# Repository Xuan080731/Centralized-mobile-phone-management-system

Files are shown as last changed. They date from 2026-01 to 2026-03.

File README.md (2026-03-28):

# 📱 集中式手機管理系統 (Centralized mobile phone management system)

> 一個集中式手機管理系統，使用 Web App 監控手機的放置狀態和環境狀態，並將資料記錄在 Google 試算表中，同時可利用 RFID 解鎖或 Web App 遠端、定時解鎖。

## 📖 專案簡介 (Introduction)

近年來，全球教育界為提升學生專注力，對於校園手機使用的規範日益嚴格。然而，傳統的手機保管箱僅具備物理存放功能，缺乏即時狀態監控、環境感測預警與數位化管理能力，若發生手機未歸位或意外狀況，管理端難以即時掌握。

基於此痛點，本專案開發了一套整合環境感測與雲端監控之集中式手機管理系統，採用 **ESP32 與 Mega2560 雙主控協作架構**，不僅實現了 20 個手機槽位的精準狀態監控，更結合了雲端 Web App，提供校園或特定高保密場所一套高效、模組化且易於維護的手機集中管理方案。

## ✨ 核心特色 (Key Features)

* **🧠 異質雙主控架構 (Dual-MCU Architecture)**
  由 Arduino Mega2560 負責 20 路微動開關的底層 I/O 實時輪詢，並交由搭載 FreeRTOS 的 ESP32 進行邊緣運算與雲端通訊，徹底解決單晶片 I/O 不足與聯網阻塞問題。
* **☁️ 可視化網頁監控 (Serverless Web Dashboard)**
  完全免架設實體伺服器！後端採用 Google Apps Script (GAS) 構建，狀態與歷史紀錄即時寫入 Google Sheets，並提供可視化的響應式 Web App，管理員可隨時隨地遠端監控手機放置情況和環境狀態並執行遠端解鎖或定時排程。
* **🔐 多元安全門禁 (Secure Access Control)**
  支援授權 RFID 卡片感應解鎖、Web App 遠端一鍵解鎖，以及自訂時間的自動排程解鎖，配合磁簧開關實現防呆關門自動上鎖。
* **🚨 主動式災防預警 (Active Emergency Response)**
  整合 MQ-135 氣體感測器即時偵測空氣品質與火災煙霧（如手機鋰電池自燃）；同時接入 **台灣中央氣象局 (CWA) 地震速報 API**。當遭遇異常煙霧或四級以上有感地震等危急情況時，系統將觸發蜂鳴器警報並強制自動解鎖，確保人員逃生時能及時取回手機，保障生命財產安全。

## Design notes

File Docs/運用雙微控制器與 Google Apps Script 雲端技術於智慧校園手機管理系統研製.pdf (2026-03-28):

運用雙微控制器與 Google Apps Script 雲端技術於智慧校園手機管理系統之研製 壹、前言

一、研究動機

近年來，全球教育界對於學生在校使用手機的限制日益趨嚴，旨在改善學 習環境並提升學生的專注力。從歐美多國到我國教育部，紛紛加強了相關政策 的推動。然而，傳統的手機保管箱僅能提供物理上的集中存放，缺乏即時監 控、教室環境感測與數位化管理的能力。一旦發生手機未歸位或其他狀況，管 理人員難以即時掌握。

基於此社會需求與技術缺口，本專題發想出「智慧手機保管箱」，目標是 設計一個具備手機放置監控、環境感測預警、RFID 解鎖、遠端解鎖、定時解 鎖及遠端 Web App 管理功能的智慧化解決方案，以滿足學校、會議室或實驗 室等場所對手機集中管理的嚴格要求。

二、研究目的

本研究旨在研製一套「主動式智慧手機管理系統」，具體目的如下：

(一)實現即時狀態監控：透過微動開關感測器，精確監測 20 個手機槽位的放置狀 態，並在外殼上的 1~20 個 LED 燈和 LCD 螢幕上與網頁即時顯示。

(二)建立安全存取機制：整合 RFID 讀取模組與推拉式電磁鎖和需 PIN 碼驗證的遠 端、定時解鎖，確保只有經過授權的人員才能解鎖保管箱。

(三)開發雲端管理平台：利用 Google Apps Script 建立 Web App 監控系統，實現遠端 查看手機狀態、溫度等環境資訊和遠端、定時解鎖，並將數據紀錄至 Google Sheets。

(四)提升安全性與主動應變能力: 整合 MQ-135 煙霧感測與中央氣象局 API 地震偵 測。當偵測到火災煙霧或四級以上地震時，系統會強制解鎖保管箱並觸發蜂鳴器警 報，確保人員能迅速取回手機，保障生命財產安全。

貳、文獻探討

一、雙微控制器架構與系統強健性分析

在物聯網（IoT）裝置的開發中，網路傳輸與硬體控制的資源分配一直是關鍵難題。根據

## Niedermaier、Merli 與 Sigl（2019）在《A Secure Dual-MCU Architecture for Robust Communication of IIoT Devices》研究中指出，傳統的單一微控制器（Single-MCU）架構在

處理複雜的加密通訊協定（如 TLS/HTTPS）時，往往會佔用大量的 CPU 運算週期，進而 導致對硬體感測器的控制產生延遲或中斷（Blocking），嚴重影響系統的即時性。

該研究進一步提出「雙微控制器架構（Dual-MCU Architecture）」作為解決方案，主張

## 將「網路通訊任務（Communication Tasks）」與「實體控制任務（Physical Control

Tasks）」進行硬體層級的解耦（Decoupling）。透過專屬的通訊晶片處理外部連線，主控制

晶片則能專注於感測器讀取與致動器控制。研究結果證實，此架構能顯著提升系統在網路不 穩定或高負載環境下的強健性（Robustness）與可用性（Availability）。

本研究在系統設計上導入 ESP32 雙核心（Dual-Core）平行運算技術。利用 FreeRTOS 進行任務調度，將 ESP32 的 核心 1（Core 1） 規劃為「本地控制核心」，專責處理 RFID 身分識別、電子鎖控制及感測器數據讀取，確保硬體操作達到即時響應；同時將 核心 0 （Core 0） 指派為「雲端通訊核心」，專門負責耗時的 Google Sheets API 連線與資料上傳 任務。此一分流設計確保了即便系統正在進行網路傳輸或遭遇網路壅塞，使用者的刷卡開鎖 等在地端操作體驗依然流暢不受影響。

二、雲端資料庫技術之選用與分析

在物聯網系統的後端資料庫選擇上，傳統的關聯式資料庫（如 MySQL、SQL Server） 雖然功能強大，但往往伴隨著高昂的伺服器架設與維護成本，對於校園專題或中小型應用而 言門檻過高。相較之下，採用雲端試算表作為輕量級資料庫已成為新興趨勢。

## 根據 Kumar、Sudharani 與 Jayavardhan（2025）在《Build Your Own RFID Attendance System Using Arduino, ESP32, and Google Sheets》的研究指出，整合 Arduino

與 ESP32 架構並利用 Google Sheets 作為後端資料庫，不僅具備零成本與高可及性的優 勢，更能透過 Google Apps Script API 實現高可靠度的即時數據登錄與監控。該研究證實， 此架構能有效消除本地端伺服器的維護負擔，同時提供穩定的數據雲端同步功能。

本研究參採此一概念，利用 Google Sheets 取代傳統伺服器，將 ESP32 的數據透過 HTTPS 協定直接寫入雲端，實現低成本且易於管理的智慧化系統。

三、智慧置物櫃與物聯網監控之應用

## Umadi 等人（2023）在《Smart E-Locker System using IoT》研究中提出了一種基於

RFID 與物聯網技術的智慧電子置物櫃系統。該研究指出，傳統置物櫃缺乏即時監控能力， 而透過整合微控制器與雲端平台（如 Adafruit Cloud），系統不僅能記錄使用者的存取日誌， 還能在偵測到未授權的 RFID 標籤時觸發警報並發送通知。這證實了將「實體鎖頭」與 「雲端紀錄」結合，能顯著提升校園或公共場域資產管理的安全性與便利性，此論點支持了 本研究將手機保管箱雲端化的設計思路。

參、研究方法

一、研究步驟

本研究的製作流程從初步構想到最終成品，歷經需求分析、設計、開發、測試與整合等 多個階段。詳細步驟如下：

（一） 初步構想與需求分析：
1. 確立研究動機：針對校園手機管理普遍存在的挑戰，如傳統保管箱缺乏效率、安全 性不足等問題，確立開發一套智慧化管理系統的目標。
2. 功能規格定義：明確系統需具備的核心功能，包括即時監控手機放置狀態、RFID 授 權解鎖、遠端解鎖、定時解鎖、遠端 Web App 管理、以及偵測到煙霧或地震等緊 急情況下的自動解鎖與警報功能。
（二） 系統設計：
1. 硬體選型：根據功能需求，選定核心微控制器（ESP32 與 Arduino Mega 2560）、感 測器（微動開關、RFID RC522、MQ-135、DHT11）、致動器（電磁閥）及其他電子 元件。
2. 架構設計：採用雙微控制器架構，將本地即時控制與雲端通訊任務分離，確保系統 的穩定性與反應速度。同時設計了包含感知層、控制層與應用層的三層式系統架 構。
3. 電路設計：使用 Fritzing 等工具繪製詳細的電路圖，規劃各元件之間的接線與供電 方式。
4. 機構設計：使用 Thinkercad 進行 3D 建模，設計保管箱的外殼與內部 20 格手機槽 位，並規劃雷射切割的板材。
（三） 開發與製作：
1. 硬體組裝：進行雷射切割、組裝保管箱外殼，並根據電路圖焊接、連接所有電子元 件。

## 2. 韌體開發：使用 Arduino IDE 撰寫 ESP32 與 Arduino Mega 2560 的程式碼，實現感測

器數據讀取、雙晶片 UART 通訊、RFID 驗證、電磁鎖控制等功能。

## 3. 雲端平台開發：利用 Google Apps Script 建立後端伺服器，並設計 Google Sheets 作

為資料庫，用於接收並儲存來自 ESP32 的數據。同時開發 Web App 前端介面，實 現遠端監控與管理。
（四） 測試與驗證：
1. 單元測試：對各個硬體模組（如 RFID、微動開關）與軟體功能（如雲端上傳）進行 獨立測試，確保其正常運作。
2. 整合測試：將所有軟硬體整合，進行全面的系統測試，包括測試雙 MCU 架構下的 效能、雲端資料同步的延遲與成功率等。
3. 壓力測試：模擬多人同時使用或網路不穩定的情況，測試系統的穩定性與強健性。

（五） 修正與優化：
根據測試結果，對硬體電路、軟體程式碼或系統架構進行調整與優化，例如優化程 式演算法以縮短反應時間等。

圖一、研究步驟甘特圖

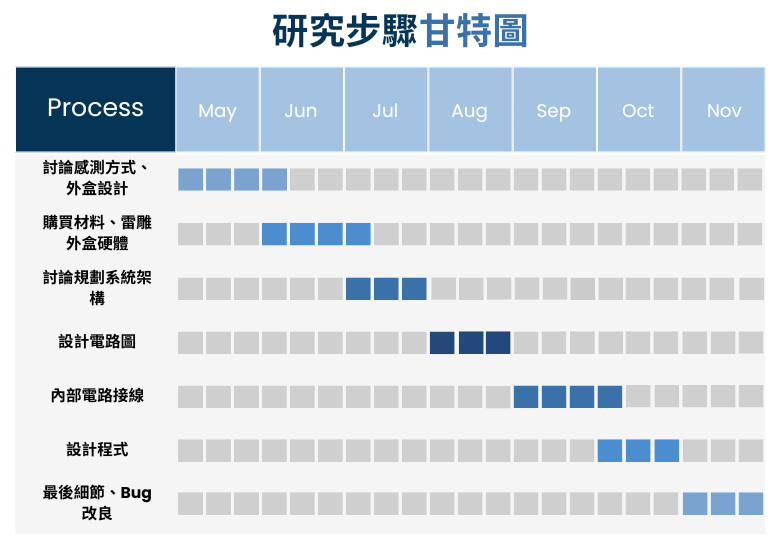
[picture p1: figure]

資料來源:使用 Canva 自行製作

圖二、初步設計模型 | 圖三、實際雷雕硬體

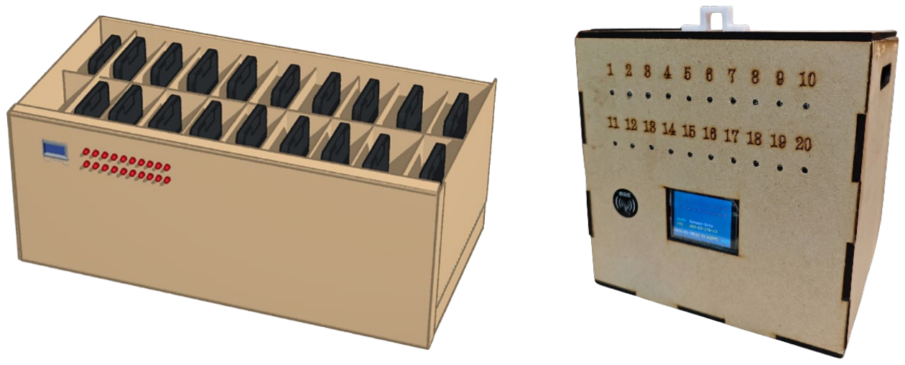
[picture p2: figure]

資料來源:使用 Thinkcad 設計初步模型 | 資料來源:自行拍攝

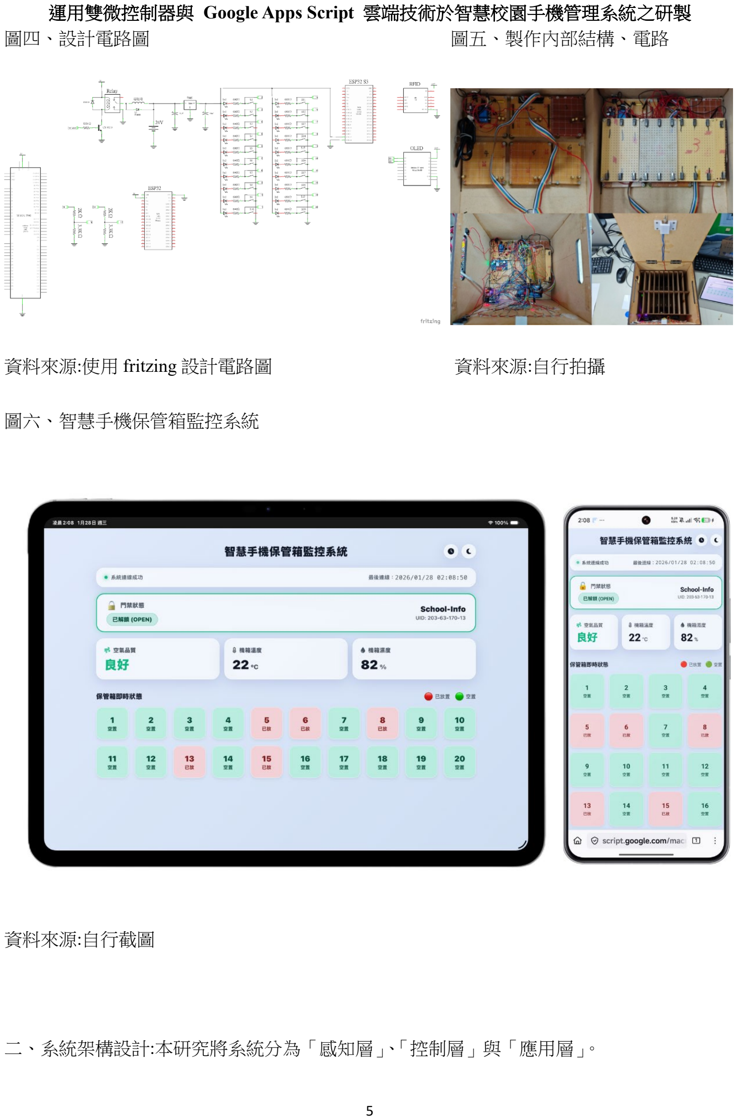
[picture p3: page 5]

圖四、設計電路圖 | 圖五、製作內部結構、電路
資料來源:使用 fritzing 設計電路圖 | 資料來源:自行拍攝

圖六、智慧手機保管箱監控系統

資料來源:自行截圖

二、系統架構設計:本研究將系統分為「感知層」、「控制層」與「應用層」。

(一) 感知層:此層負責實體環境與硬體狀態的數據採集，並執行身分識別

1. 手機狀態偵測：於 20 個手機櫃位內部各配置獨立微動開關，當手機置入或取出時觸發 物理開關，將實體動作轉換為數位高低電位訊號。
2. 身分識別模組：採用 RFID RC522 射頻識別模組，透過讀取使用者授權 UID，作為開 啟電子鎖安全驗證。
3. 環境安全感測：整合 MQ-135 氣體感測器與 DHT11 溫濕度感測器，即時監控保管箱 周遭的空氣品質、煙霧感測與溫濕度變化。

(二) 控制與運算層:為解決單一微控制器處理複雜任務造成的阻塞問題與腳位不夠問題，

採用雙微控制器協同架構，包含兩大運算核心。

## 1. I/O 協同處理單元 (Arduino Mega 2560)： 作為放置訊號採集，專責執行 20 個櫃位微

動開關的高頻率輪詢（Polling）掃描。其負責將龐大且零碎的 I/O 訊號預處理後，轉 換為特定格式之字串，透過 UART 序列埠穩定傳送至 ESP32 主控單元。

2. 通訊主控單元 (ESP32)： 作為系統的運算大腦與聯網樞紐。藉助其內建的 FreeRTOS 作業系統實現多工處理 ：
- Core 1 (即時控制)： 負責解析 Mega 2560 傳入之字串、處理 RFID 驗證、驅 動 24V 電磁閥執行解鎖動作，並同步控制 2.8 吋 SPI LCD 顯示螢幕及 20 顆外部 LED 指示燈，確保本地端操作具備極低延遲 。
- Core 0 (網路通訊)： 專責透過 Wi-Fi 建立 HTTPS 加密連線，負責將彙整後 之感測數據與系統狀態封裝，利用 HTTP GET 請求上傳至雲端；同時背景查 詢中央氣象署 API，判斷地震等突發狀況以觸發緊急安全機制 。

(三) 應用與儲存層: 此層負責雲端數據處理、持久化儲存與遠端人機介面互動：

## 1. 雲端伺服器 (Google Apps Script)：作為後端處理中心，接收並解析 ESP32 傳送之

RESTful API 請求。除了處理資料上傳外，亦負責下發遠端解鎖或定時解鎖指令給 ESP32。
2. 資料庫 (Google Sheets)： 作為輕量級雲端資料庫，即時且永久性地記錄 20 個槽位之狀 態、環境溫濕度、空氣品質指數以及 RFID 或遠端解鎖之時間與人員歷史資訊，便於管理端 進行查詢。
3. 可視化管理介面 (Web App)： 透過 HTML5/CSS3 開發響應式網頁（RWD），並結合密 碼（PIN 碼）驗證機制。提供教師或管理員於任何瀏覽器上，直觀且即時地檢視手機放置狀

態（綠燈/紅燈）、查閱環境資訊，並執行遠端授權、定時解鎖操作。

圖七、系統架構圖

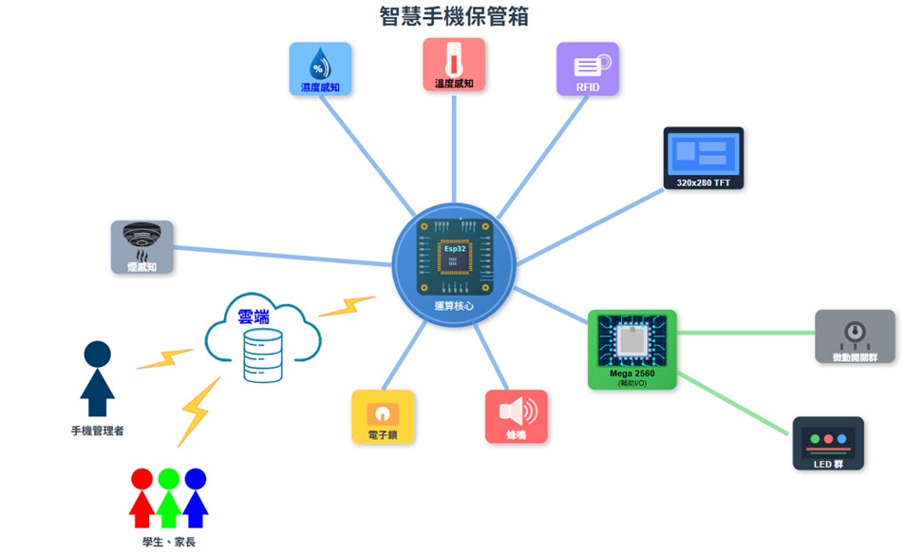
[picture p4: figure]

資料來源:自行製作

三、製作材料與硬體清單

表一、製作材料與硬體清單

類 別 | 項目 | 數 量 | 功能說明 | 價格 (NTD)
主 控 單 元 | ESP32 開發板 | 1 | 負責雙核心分流、WiFi 連線與 HTTPS 雲端資料上傳、控制電磁鎖、驅動 LCD 顯示。 | $150

類 別 | 項目 | 數 量 | 功能說明 | 價格 (NTD)
主 控 單 元 | Arduino Mega 2560 | 1 | 負責掃描 20 個櫃位微動開關狀態，具 備充足 I/O 腳位。 | $350
感 測 元 件 | RFID RC522 模 組 | 1 | 執行使用者身分識別與解鎖驗證。 | $60
感 測 元 件 | 微動開關 (KW12-3) | 20 | 安裝於櫃位內，偵測手機是否確實放 入。 | $60
感 測 元 件 | 溫濕度感測器 (DHT11) | 1 | 溫濕度感測。 | $15
感 測 元 件 | 空氣質量感測器 (MQ-135) | 1 | 空氣品質、氣體檢測。 | $50
感 測 元 件 | 磁簧開關 | 1 | 偵測箱門實體開關狀態，確保門關妥後 才執行電磁鎖閉鎖。 | $45

類 別 | 項目 | 數 量 | 功能說明 | 價格 (NTD)
控 制 元 件 | 電磁閥 (24V) | 1 | 執行櫃門實體解鎖動作。 | $250
輸 出 模 組 | 2.8 吋 SPI LCD 顯示模組 | 1 | 即時顯示解鎖狀態與手機放置狀態等資 訊。 | $120
輸 出 模 組 | 高亮度紅色 LED | 20 | 20 顆 LED 對應保管箱的 20 個格 位，作為狀態指示燈，用來即時顯示每 個格子是否已放入手機（佔用或空閒狀 態），讓使用者一目了然。 | $20
輸 出 模 組 | 有源蜂鳴器 | 1 | 提供刷卡、解鎖之操作音效提示；於偵 測到異常氣體或地震時發出警報音。 | $15
電 源 系 統 | 680 歐姆電阻 | 20 | 負責限制流經 LED 的電流大小，保護 LED 不會因為電流過大而燒毀。 | $5
電 源 系 統 | 2K、3.3K 歐姆 電阻 | 1 | 負責解決 Arduino Mega 2560 與 ESP32 工作電壓不同（邏輯電位不匹配）的問 題，保護 ESP32 不被燒毀。 | $1

類 別 | 項目 | 數 量 | 功能說明 | 價格 (NTD)
電 源 系 統 | XL4015 可調降 壓電源模塊 | 1 | 將用於電磁閥的 24V 電源轉為其他元件 可承受的 5V 電源。 | $200
電 源 系 統 | 24V5A 電源適 配器 | 1 | 用於供電。 | $200
機 構 材 料 | 杜邦線 | 100 | 連接各個元件。 | $100
機 構 材 料 | PCB 萬用電路 板 | 7 | 焊接/放置各種電路元件。 | $100
機 構 材 料 | 合成木板外盒 | 1 | 系統載體與手機放置格位。 | $1000
總 計 | | | 本系統研製總材料成本 | $2740

資料來源:自行計算

肆、研究分析與結果

一、雙微控制器與單晶片之效能比較

本研究實際測試「單晶片直接聯網」與「雙 MCU 架構」在操作反應時間上的差異。

表二、實際測試「單晶片直接聯網」與「雙 MCU 架構」在操作反應時間上的差異

測試項目 | 單晶片架 構 | 本研究雙 MCU 架 構 | 效能差異分 析
放置/拿取手機反應時間 (放入偵測到 LCD 顯示) | 約 1.85 秒 | 0.15 秒 | 快 12 倍
手機箱解鎖時間 (刷卡到電磁鎖彈開) | 約 3.12 秒 | 0.18 秒 | 快 17 倍
上傳顯示延遲 (動作發生到 Google Sheet 出現 資料) | 約 9 秒 | 4.4 秒 | 快 2 倍

資料來源:自行實驗結果

二、與傳統保管箱之比較分析

為凸顯本研究所開發之智慧校園手機管理系統的實用性與創新價值，我們將其與傳統的校園 手機保管箱進行多面向的比較分析。傳統保管箱雖然在各地校園行之有年，但其功能單一， 僅提供基本的集中收納，缺乏現代教育管理所需的智慧化與安全性。詳細比較如下表所示：

表三、與傳統保管箱之比較分析

功能 面向 | 傳統手機保管箱 | 本研究之智慧校園手機管理系統
狀態 監控 | 無法得知手機是否確實 放入 | 即時監控：透過 Web App 與 LED 燈號，可立即掌握每 個槽位的放置狀態。
管理 方式 | 人工點名、鑰匙管理 | 雲端平台：提供 Web App，讓管理者可遠端即時查看、 管理，並自動記錄存取日誌。
存取 安全 | 僅有簡易機械鎖，鑰匙 易遺失或複製 | 多重驗證：整合 RFID 卡片授權與遠端 PIN 碼解鎖，安 全性高。
緊急 應變 | 無 | 主動預警：整合煙霧與地震偵測，發生緊急狀況時自動 解鎖以供取出手機並發出警報。
管理 效率 | 耗時費力，需逐一確認 | 高效率：管理者可一目了然，大幅減少清點與管理的人 力成本。
擴充 彈性 | 固定規格，無法擴充 | 模組化設計：可根據班級人數需求，彈性擴充管理容 量。

資料來源:經驗統整

伍、研究結論與建議

一、結論

本研究成功研製一套基於 ESP32 與 Arduino Mega 2560 雙微控制器驅動之校園智慧手 機管理系統。實驗結果證實，透過雙核心任務分流架構，本系統能有效解決單晶片聯網時的 阻塞問題，將操作反應時間大幅縮短至 0.15 秒以內。在硬體架構方面，本系統採用模組化 設計，雖本研究之原型機以 20 格作為功能驗證，但其 I/O 控制邏輯具備高度可擴充性。 在實際應用場域中，僅需串聯偵測模組即可將管理容量擴充至標準班級規模（如 30 格或更 多），而無須更動核心控制系統。本研究不僅以低於市售電子櫃 2 倍之成本（約新台幣 2700 元）達成智慧化與集中式管理之目標，更大幅提升了校園手機管理的清點效率與安全 性。

二、建議

(一)系統管理介面之優化

建議未來可開發專屬的行動裝置應用程式（APP），整合推播通知功能，當學生逾時未放 入手機時，系統可主動發送訊息提醒管理員，從被動監控轉為主動預警。

(二)導入生物辨識功能

本研究目前採用 RFID 技術作為主要辨識載具，雖具備操作簡便之優點，但仍可能面臨 管理員遺失卡片或代為刷卡之管理風險 。建議未來可規劃導入生物辨識模組，例如：
- 人臉辨識：利用 ESP32-CAM 模組結合輕量化 AI 運算模型（如 TinyML），在邊緣 端實現視覺辨識，確保存取者的身分為本人，進一步提升系統的安全性。

陸、參考文獻

## Niedermaier, M., Merli, D., & Sigl, G. (2019). A Secure Dual-MCU Architecture for Robust

Communication of IIoT Devices. arXiv preprint arXiv:1908.04133.

Kumar, L. N., Sudharani, K., & Jayavardhan, L. (2025). Build your own RFID attendance system using Arduino, ESP32, and Google Sheets. International Journal of Scientific Development and Research, 10(8), 448-455.

Umadi, K. R., Inchara, S. M., Jyothi, E., & Narendramath, E. (2023). Smart E-Locker System using IoT. 2023 International Conference on Intelligent Data Communication Technologies and Internet of Things (IDCIoT), 415-419.

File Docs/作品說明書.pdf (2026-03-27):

## 智慧手機保管箱說明書

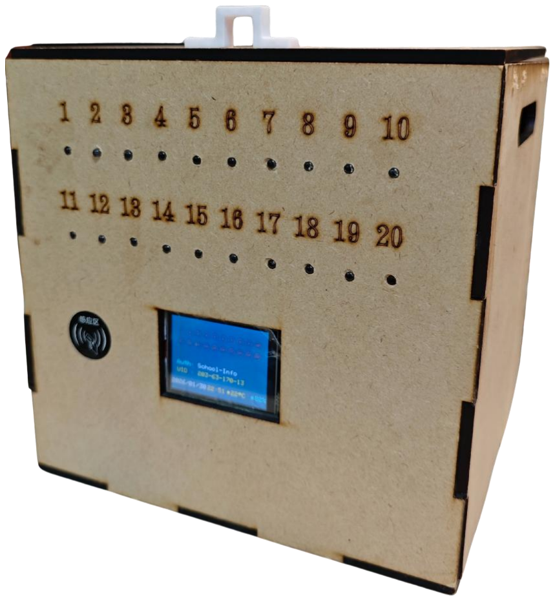
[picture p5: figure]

## 關 鍵 詞： 物聯網、手機管理、環境監控

目錄

項目 | 頁數

### 壹、 創意動機及目的

| 一、 動機 - - - - - - - - - - - - - - - - - - - - - - - - - - 1
| 二、 目的 - - - - - - - - - - - - - - - - - - - - - - - - - - 1

### 貳、 作品特色及創意特質

| 一、 輕量級雲端監控 Web App - - - - - - - - - - - 1,2
| 二、 直觀方便檢視放置狀態 - - - - - - - - - - - - - 2
| 三、 安全性與主動應變能力 - - - - - - - - - - - - - 3
| 四、 模組化與實用性設計 - - - - - - - - - - - - - - 3

### 參、 創意發想與設計過程

| 一、 問題探索與需求蒐集 - - - - - - - - - - - - - - 4
| 二、 設計流程 - - - - - - - - - - - - - - - - - - - - - - 4~6

### 肆、 設計相關原理

| 一、 雙主控單元協作架構 - - - - - - - - - - - - - - 7
| 二、 雲端數據傳輸原理 - - - - - - - - - - - - - - - - 8
| 三、 MQ-135 氣體數值演算法與動態校正邏輯 8,9
| 四、 TFT LCD 自製中文轉點陣生成工具 - - - - 9,10
| 五、 硬體結構與控制原理 - - - - - - - - - - - - - - 10,11

項目 | 頁數

### 伍、作品功用與操作方式

| 一、 作品功用 - - - - - - - - - - - - - - - - - - - - - - - 11,12
| 二、 操作方式 - - - - - - - - - - - - - - - - - - - - - - - 12

### 陸、製作歷程說明

| 三、 硬體製作流程 - - - - - - - - - - - - - - - - - - - 12~14
| 四、 軟體開發流程 - - - - - - - - - - - - - - - - - - - 14,15

柒、參考資料 - - - - - - - - - - - - - - - - - - - - - - - - - 15

### 壹、創意動機及目的

一、動機

近年來，全球教育界對於學生在校使用手機的限制日益趨嚴，旨在改善學習環 境並提升學生的專注力。從歐美多國到我國教育部，紛紛加強了相關政策的推 動。然而，傳統的手機保管箱僅能提供物理上的集中存放，缺乏即時監控、教 室環境感測與數位化管理的能力。一旦發生手機未歸位或其他狀況，管理人員 難以即時掌握。

基於此社會需求與技術缺口，本專題發想出「智慧手機保管箱」，目標是設計 一個具備手機放置監控、環境感測預警、RFID 解鎖及遠端 Web App 管理功能 的智慧化解決方案，以滿足學校、會議室或實驗室等場所對手機集中管理的嚴 格要求。

二、目的

(一)實現即時狀態監控：透過微動開關感測器，精確監測 20 個手機槽位的放置 狀態，並在外殼上的 1~20 個 LED 燈和 LCD 螢幕上與網頁即時顯示。

(二)建立安全存取機制：整合 RFID 讀取模組與推拉式電磁鎖和需 PIN 碼驗證的 遠端、定時解鎖，確保只有經過授權的人員才能解鎖保管箱。

(三)開發雲端管理平台： 利用 Google Apps Script 建立 Web App 監控系統，實 現遠端查看手機狀態、溫度等環境資訊和遠端、定時解鎖，並將數據紀錄至 Google Sheets。

(四)提升安全性與主動應變能力: 整合 MQ-135 煙霧感測與中央氣象局 API 地震 偵測。當偵測到火災煙霧或四級以上地震時，系統會強制解鎖保管箱並觸發蜂 鳴器警報，確保人員能迅速取回手機，保障生命財產安全。

### 貳、作品特色及創意特質

一、輕量級雲端監控 Web App

- 無需專門伺服器： 藉助 Google 服務的免費與穩定性，大幅降低了系統部 署與維護成本。

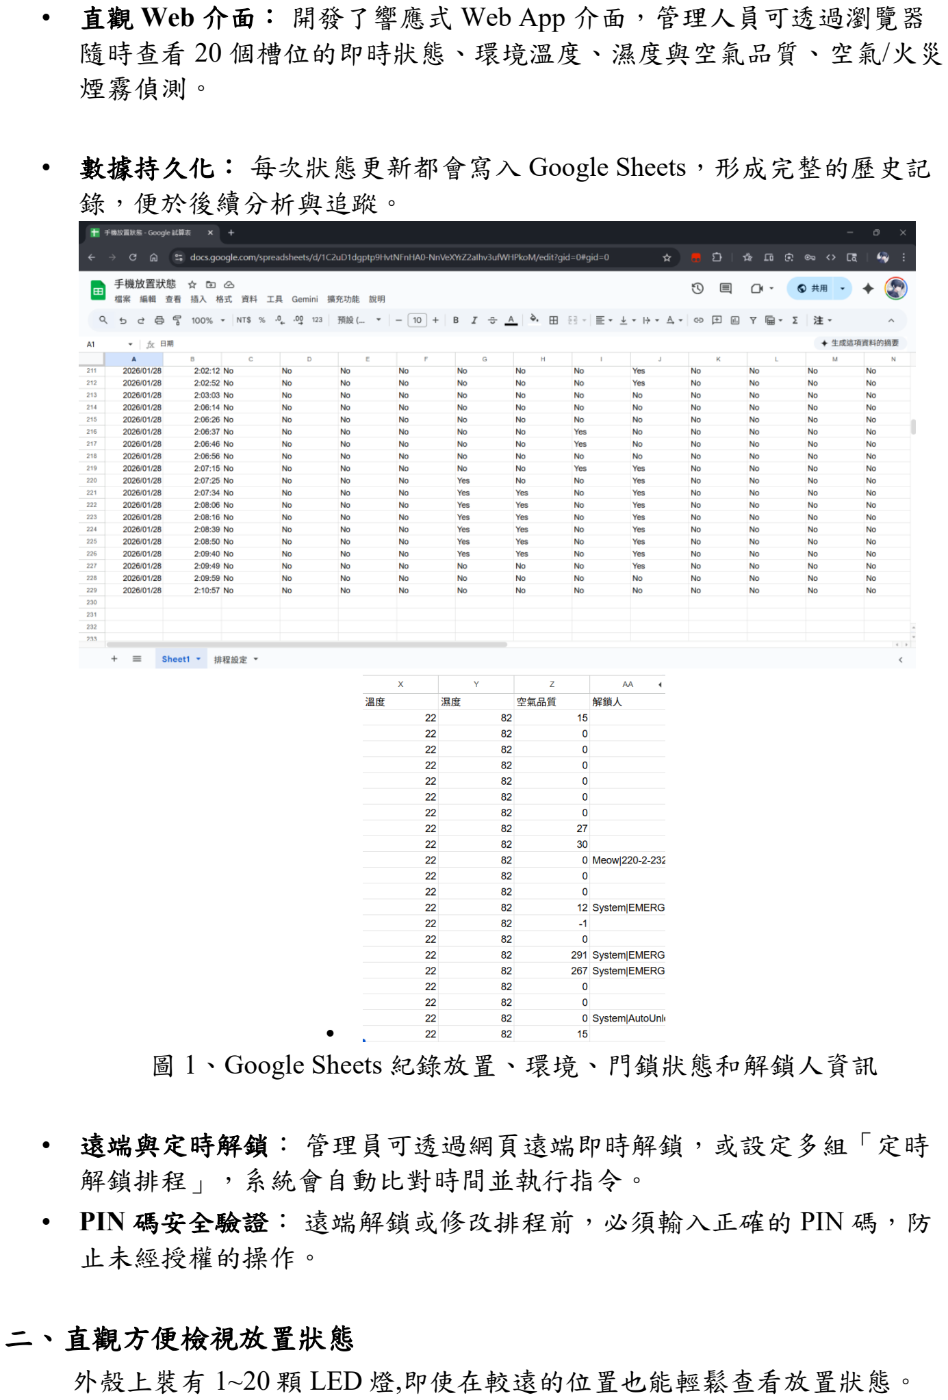
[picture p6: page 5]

- 直觀 Web 介面： 開發了響應式 Web App 介面，管理人員可透過瀏覽器 隨時查看 20 個槽位的即時狀態、環境溫度、濕度與空氣品質、空氣/火災 煙霧偵測。
- 數據持久化： 每次狀態更新都會寫入 Google Sheets，形成完整的歷史記 錄，便於後續分析與追蹤。

•
圖 1、Google Sheets 紀錄放置、環境、門鎖狀態和解鎖人資訊
- 遠端與定時解鎖： 管理員可透過網頁遠端即時解鎖，或設定多組「定時 解鎖排程」，系統會自動比對時間並執行指令。
- PIN 碼安全驗證： 遠端解鎖或修改排程前，必須輸入正確的 PIN 碼，防 止未經授權的操作。

二、直觀方便檢視放置狀態
外殼上裝有 1~20 顆 LED 燈,即使在較遠的位置也能輕鬆查看放置狀態。

三、安全性與主動應變能力

整合 MQ-135 煙霧感測與中央氣象局 API 地震偵測。當偵測到火災煙霧 或四級以上地震時，系統會強制解鎖保管箱並觸發蜂鳴器警報，確保人 員能迅速取回手機，保障生命財產安全。

四、模組化與實用性設計

在硬體設計上，注重實用性與維護性：

- 模組化微動開關面板： 底部微動開關電路板採用模組化設計，方 便在損 壞時進行單獨更換與維護。
- 高度擴充性設計： 系統採用模組化設計，未來可輕鬆增加更多感測器或 擴充手機槽位數量，具備極高的應用彈性與升級潛力。

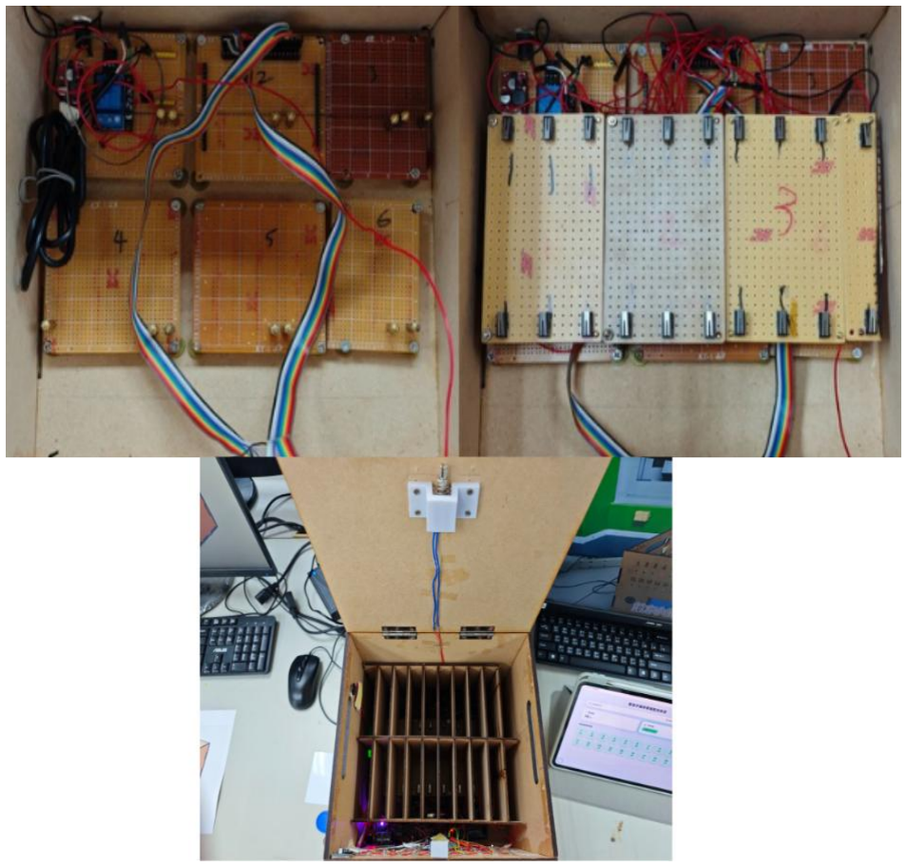
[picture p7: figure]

圖 2、內部結構圖片

### 參、創意發想與設計過程

一、問題探索與需求蒐集

初期階段，針對傳統手機保管箱的痛點進行了深入分析，並蒐集了校園手機管 理的需求。發現主要問題在於缺乏即時監控、環境安全預警和彈性管理。基於 這些需求，我們確立了「智慧手機保管箱」的設計目標，並開始構思其核心功 能，如手機狀態監控、環境感測、遠端解鎖等。我們的設計過程從解決這些核 心問題出發：
(一) 需求分析：即時監控每個槽位的狀態。
解決方案 : 採用 20 個微動開關，並由 Mega2560 專責採集與 預處理。
(二) 需求分析：遠端、低成本的數據記錄與遠端監控、操作。 解決方案 : 整合 ESP32 的 Wi-Fi 功能與 Google Apps Script，利用 Google Sheets 實現雲端數據庫與 Web App 介面。 (三)需求分析：結構堅固且易於維護。
解決方案 : 採用雷雕木板外殼與模組化內部結構，確保結 構穩定性與維護便利性。
(四)需求分析：提升安全性與主動應變能力。
解決方案: 整合 MQ-135 煙霧感測與中央氣象局 API 地震偵測。當偵 測到火災煙霧或四級以上地震時，系統會強制解鎖保管箱
並觸發蜂鳴器警報，確保人員能迅速取回手機，保障生命
財產安全。
二、設計流程

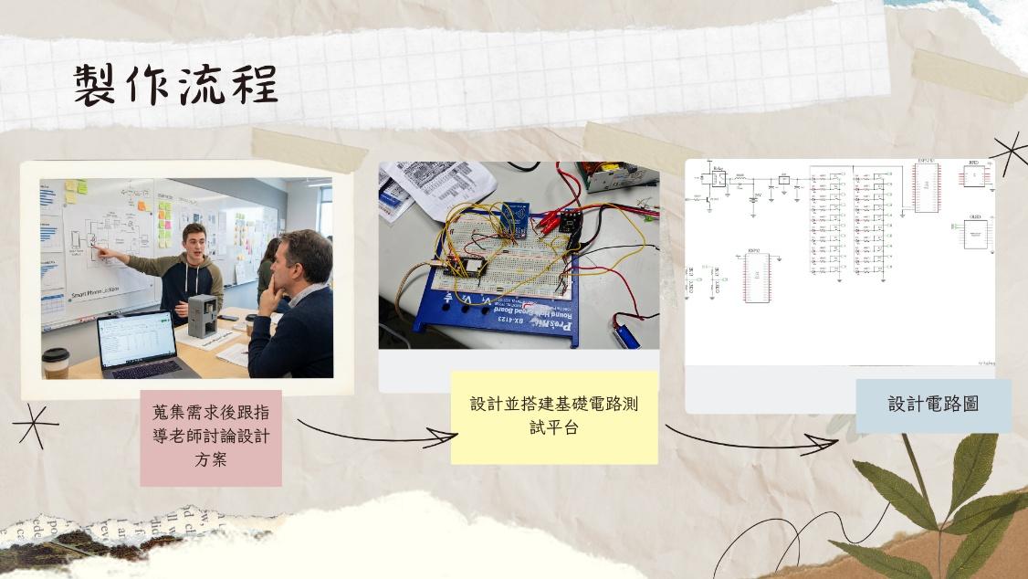
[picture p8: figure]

圖 3、設計流程圖

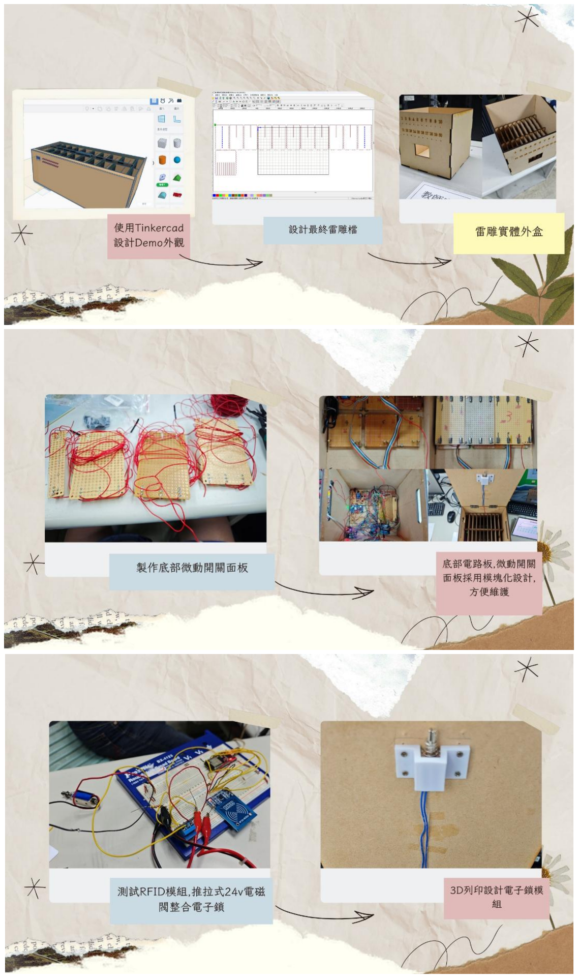
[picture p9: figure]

圖 4、設計流程圖

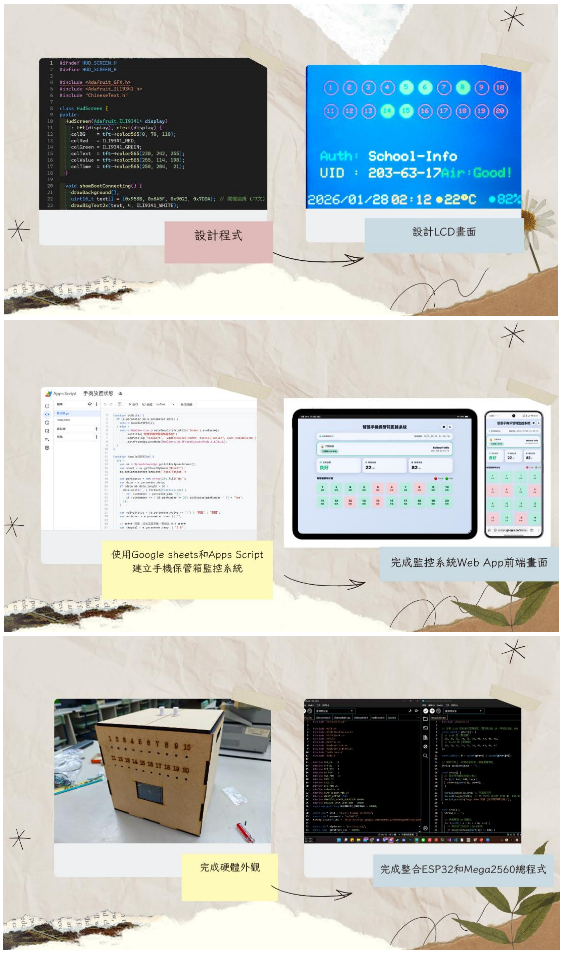
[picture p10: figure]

圖 5、設計流程圖

### 肆、設計相關原理

一、雙主控單元協作架構

為了解決單一微控制器在處理大量感測器數據、複雜通訊協定（Wi-Fi、 HTTP）和即時監控時遇到的腳位不足和效能瓶頸，本專題採用了 ESP32 與 Mega2560 的雙主控單元協作架構：

模組 | 職責劃分 | 核心功能

ESP32 (主控單
元)

負責系統核心
控制與雲端連
線

Wi-Fi 連線、HTTP 請求上傳數據、RFID
讀取、LCD 顯示、UART 通訊、MQ-135,DHT11 環境即時監控、控制電磁鎖。

Mega2560 (協同
單元)

負責大量數據
採集與預處理

監測 20 個微動開關訊號、處理訊號邏
輯、透過 UART 傳送狀態給 ESP32。

此架構有效分散了運算負載，確保了系統的穩定性與即時反應能力。

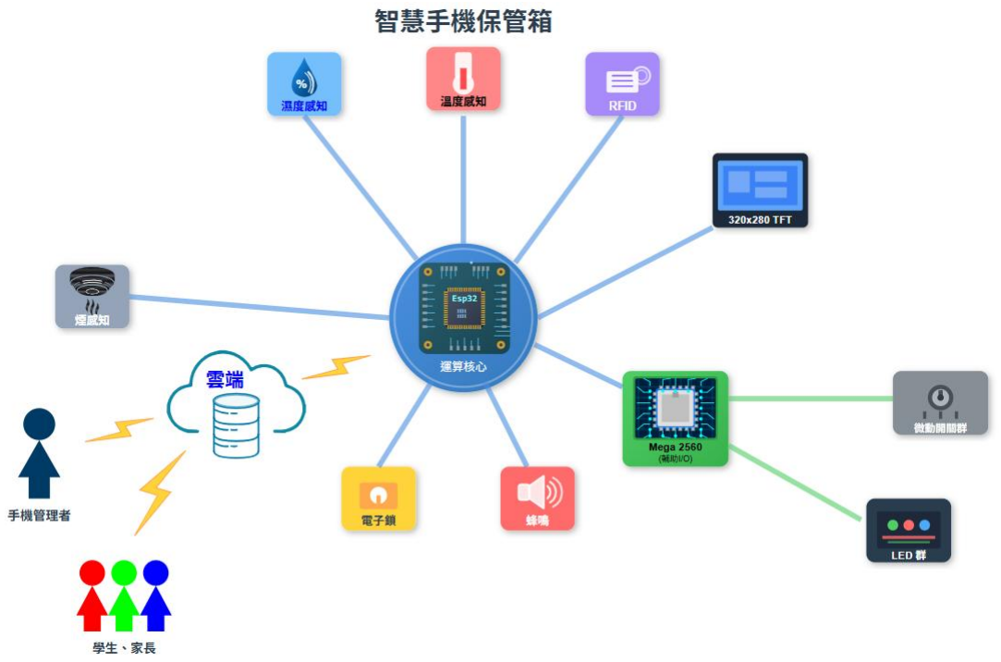
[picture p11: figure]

圖 6、系統架構圖

二、雲端數據傳輸原理

本系統採用 RESTful API GET 請求的方式，將 ESP32 採集到的狀態數據（包括 20 個槽位狀態、環境溫度等）封裝後，定期傳送至部署在 Google Apps Script 上 的 Web App URL。

- Google Apps Script (GAS)： 作為 Web App 伺服器，接收 ESP32 的 RESTful API GET 請求。
- Google Sheets： GAS 腳本解析接收到的數據，並利用 Sheets API 將數據 寫入 Google Sheets 的特定儲存格，實現數據持久化與遠端監控。
- 遠端解鎖： 使用者在 Web App 輸入 PIN 碼執行後，GAS 會在試算表的 特定儲存格標記指令。當 ESP32 下一次發送數據請求時，GAS 會在回傳 字串中加入解鎖指令，ESP32 接收後立即執行。
- 定時解鎖： GAS 會讀取試算表中的時間列表，並與當前系統時間比對。 若匹配成功，則將解鎖指令下發至硬體端。

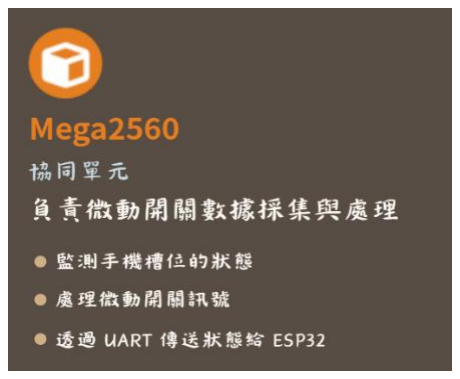
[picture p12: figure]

圖 7、主要系統分工圖

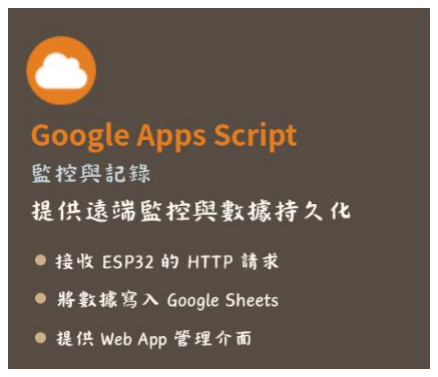
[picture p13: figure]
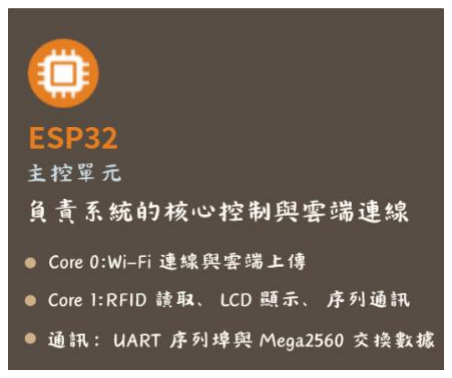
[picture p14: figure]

三、MQ-135 氣體數值演算法與動態校正邏輯 為避免感測器因雜訊或環境溫濕 度變化產生誤報，本系統在程式中實作了多層次的訊號處理演算法，而非直接 讀取原始電壓值：
(一)中位數濾波（Median Filtering）： 為了消除電路中的突波雜訊，程式每次 讀取會連續採樣 13 次類比訊號，將數值排序後取最中間的數值（Median）作為 該次採樣結果。此法能有效過濾掉瞬間的極端值干擾。
(二)開機預熱與基線校正（Warm-up & Baseline Calibration）： 感測器通電初 期需加熱氧化錫材料，程式設定了 25 秒的「預熱期」。預熱結束後，系統會連 續採樣 20 次環境數值並取平均，將其鎖定為當下的「環境基線 （Baseline）」。這確保了系統能適應不同地點的背景空氣品質。

(三)加權移動平均濾波（Weighted Moving Average）： 為了讓數值曲線平滑， 採用了「指數平滑法」： 公式：新顯示值 = (舊顯示值 × 0.6) + (新採樣值 ×
0.4) 透過 60% 的歷史權重與 40% 的新值權重，消除數據抖動，使數值變化更加 線性穩定。
(四)差分放大與靈敏度增益（Differential Amplification & Gain）： 系統判斷的 依據並非絕對電壓，而是「當前數值」與「基線」的差值。 公式：偵測值 = (平滑後數值 - 基線) × 訊號增益(Gain) 本系統設定增益為 3 倍，能將微小的煙霧 變化放大，一旦計算後的偵測值超過設定閾值（如 Fire_Threshold = 110），即 觸發緊急程序。

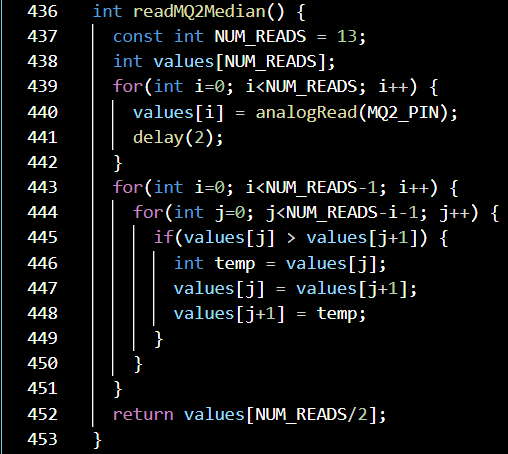
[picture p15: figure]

圖 8、氣體感測訊號處理演算法

四、TFT LCD 自製中文轉點陣生成工具
為了解決 ESP32 微控制器內部 Flash 記憶體有限，無法容納數 MB 大小的完整 中文字庫（如 BIG5 或 GB2312）之問題，本專題開發了一套輕量化顯示方案： (一) 按需取字： 僅針對系統介面中會出現的特定關鍵字（如：「系統 連線成功」、「開啟」、「關閉」、「空氣品質」等），建立專屬的微 型字庫，而非載入整套字體。
(二) 向量轉點陣技術： 該工具能夠讀取電腦系統中的 TrueType (TTF) 向量字型，並根據使用者輸入的特定字串（如：「系統連線成功」、 「開啟」），將向量路徑即時渲染為指定解析度（如 16x16 或 24x24 像素）的點陣圖形。
(三) 二值化與掃描編碼： 工具將渲染後的點陣圖進行二值化處理 （0/1），並依照 TFT 驅動 IC（ILI9341）所需的寫入順序（如：由左至 右、由上至下），將像素點轉換為十六進位的 Byte 陣列。

(四) 自動化生成標頭檔： 軟體最終自動生成 C/C++ 語言格式的 .h 標頭 檔，並加入 PROGMEM 屬性。這使得 ESP32 編譯時能將字型數據直 接存放在程式記憶體中，實現「按需取字」，將記憶體佔用降至最低。

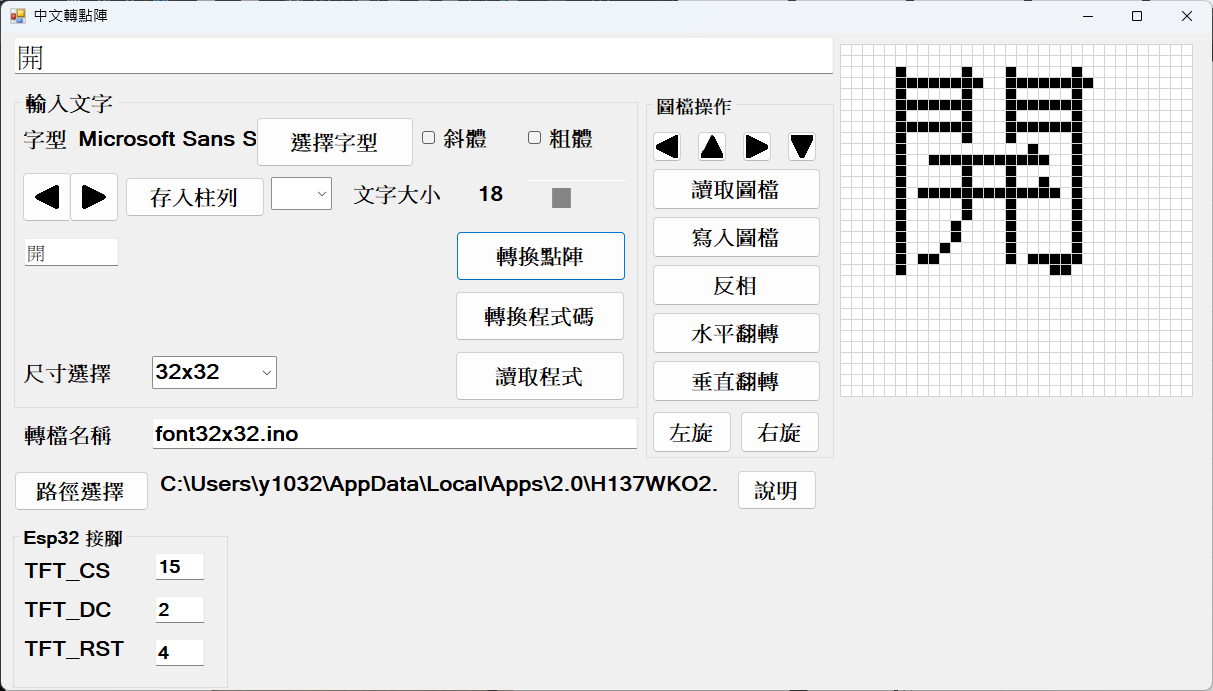
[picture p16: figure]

圖 9、自製中文轉點陣工具

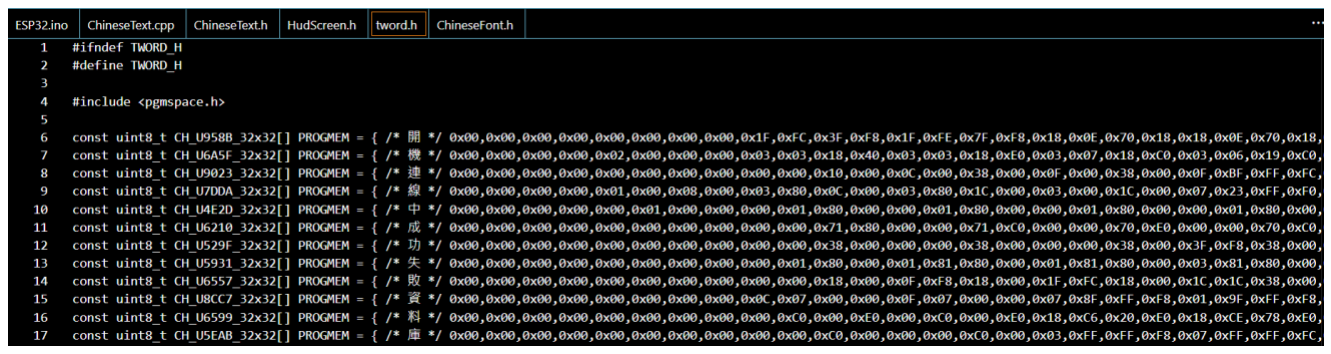
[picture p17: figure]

圖 10、簡易字庫

五、硬體結構與控制原理

- 手機放置感測： 每個槽位底部安裝微動開關。當手機放置時，開關被壓 下（狀態 1）；取出時，開關彈起（狀態 0）。Mega2560 負責讀取這 20 個開關的狀態並傳輸至 ESP32。

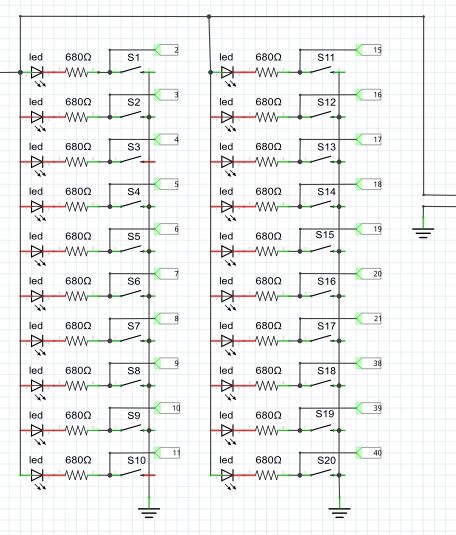
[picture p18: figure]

圖 11、1~20 格電路圖
- 安全解鎖機制： 採用 RFID 模組進行身份驗證。ESP32 讀取 RFID 卡片 的 UID，與預設的授權列表比對。驗證成功後，ESP32 驅動繼電器，向 24V 推拉式電磁鎖供電，電磁鎖吸入，實現解鎖。

### 伍、作品功用與操作方式

一、作品功用

「智慧手機保管箱」提供了一個高效、透明、可追溯的手機集中管理解決方 案，主要功用如下：

- 提升管理效率： 管理人員無需逐一檢查，透過 Web App 即可一目瞭然地 掌握所有槽位的即時狀態。

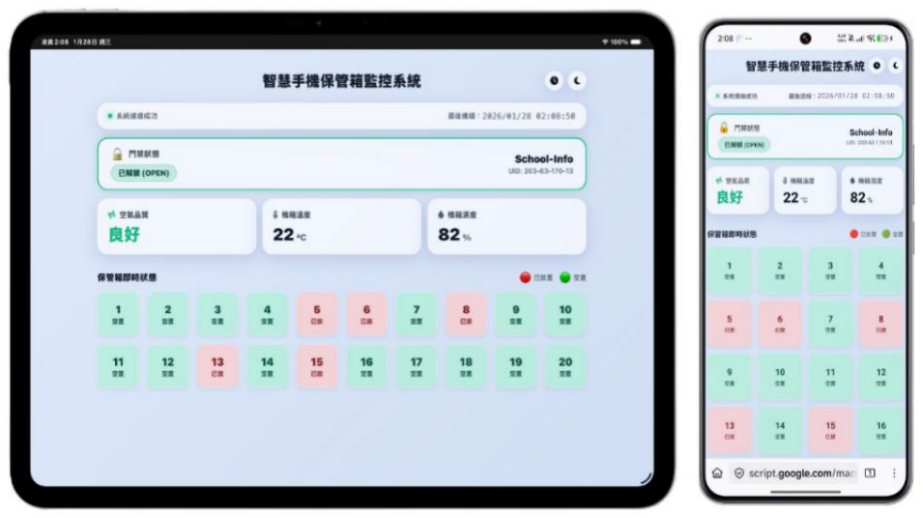
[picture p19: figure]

圖 12、Web App 多端介面適配

- 確保手機歸位： 透過即時監控與數據記錄，有效約束使用者在規定時間 內將手機歸位。
- 數據化追蹤： 所有手機的存取記錄與狀態變化均被記錄在 Google Sheets 中，便於事後追蹤與分析。
- 安全性與主動應變能力: 整合 MQ-135 煙霧感測與中央氣象局 API 地震偵 測。當偵測到火災煙霧或四級以上地震時，系統會強制解鎖保管箱並觸 發蜂鳴器警報，確保人員能迅速取回手機，保障生命財產安全。
- 模組化維護： 模組化的硬體設計，降低了設備維護的複雜度與成 本。

二、操作方式

本系統的操作方式分為使用者端（學生/員工）與管理員端（教師/管理人員）：

角色 | 操作步驟 | 系統回饋

使用
者端

1.將手機放入指定槽
位。
2.取出手機。

1.槽位狀態由「空」變為「佔用」，數據上
傳雲端。
2.槽位狀態由「佔用」變為「空」，數據上
傳雲端。

管理
員端

1.使用授權 RFID 卡片
刷卡、Web App 輸入
PIN 碼直接解鎖或定時
解鎖。
2.透過瀏覽器訪問
Google Sheets 或前端
Web App 介面。

1.驗證成功，電子鎖開啟。
2.顯示 20 個槽位的即時狀態（綠/紅）、環
境、門鎖狀態與歷史記錄。

### 陸、製作歷程說明

一、硬體製作流程

硬體設計與製作:使用 Tinkercad 進行保管箱的 3D 外觀初步設計，並利用 Adobe Illustrator 製作雷雕檔案，確保結構精準。

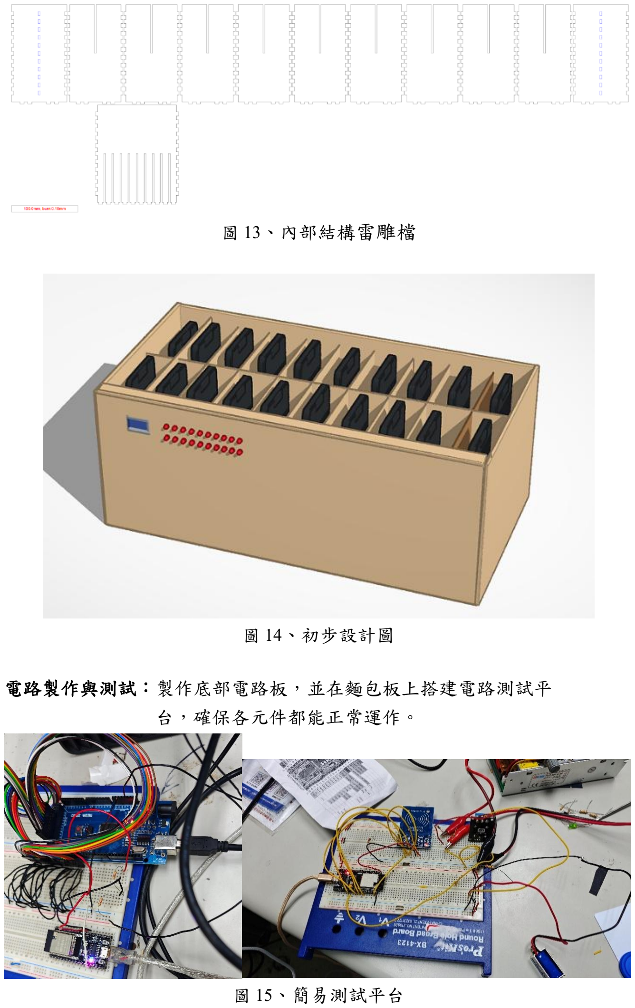
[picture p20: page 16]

圖 13、內部結構雷雕檔

圖 14、初步設計圖

電路製作與測試：製作底部電路板，並在麵包板上搭建電路測試平 台，確保各元件都能正常運作。

圖 15、簡易測試平台

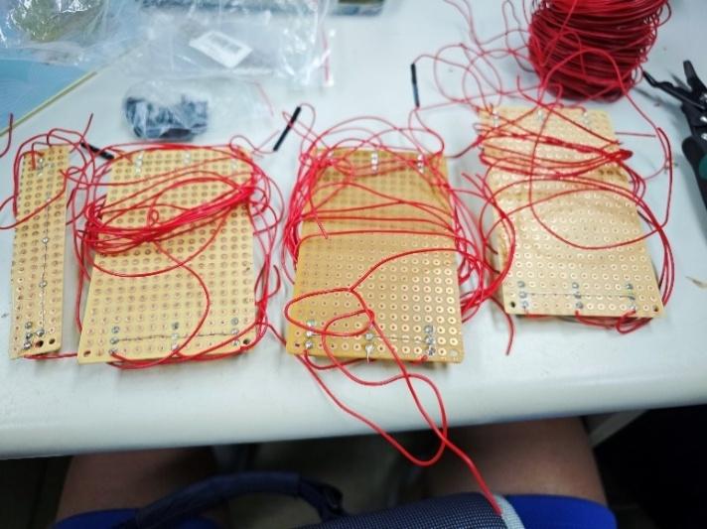
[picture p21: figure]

圖 16、微動開關底板製作
電子鎖整合：採用 24V 推拉式電磁閥作為電子鎖，並設計 3D 列印模組將 其固定在箱體內，實現 RFID 刷卡解鎖功能。

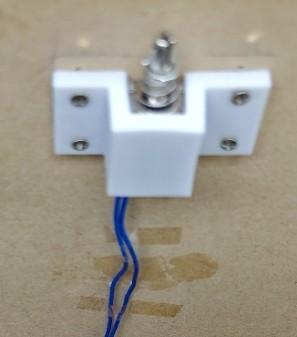
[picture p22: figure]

圖 17、3D 列印電磁鎖模組

二、軟體開發流程

(一) 第一階段：通訊協定制定
為確保 Arduino Mega 2560 與 ESP32 雙晶片間資料傳輸的正確性，首先定 義 UART 序列通訊的資料封包格式。
- 封包結構： 採用自定義 CSV 格式字串，確保資料可讀性與擴充性。
- 交握機制： 設計 Checksum 檢核碼，防止因訊號干擾導致的資料錯亂。 (二) 第二階段：Arduino Mega 2560 底層驅動開發 (I/O Scanning) 此階段專注於 20 通道感測器的高速掃描邏輯。
- 輪詢演算法 (Polling)： 撰寫高效能迴圈，每 50ms 掃描一次 20 組微動開 關狀態。

(三) 第三階段：ESP32 多核心任務分流
為解決單晶片聯網時造成的 3 秒阻塞延遲，導入 FreeRTOS 即時作業系統 進行任務分流：
- Core 1 (高優先權任務)： 負責維持系統即時回應。
- 專責監聽 UART 訊號（接收 Mega 傳來的刷卡資料）。
- 驅動電磁鎖，確保刷卡後立即開門。
- 監聽 MQ-135 煙霧數值，若數值超標立即強制開鎖。
- 利用非阻塞式計時器，每 2 秒讀取 DHT11 溫濕度數值，並暫存於 共用記憶體中，供 Core 0 讀取上傳。
- Core 0 (聯網任務)： 負責耗時的網路請求。
- 透過 Wi-Fi Client Secure 建立 HTTPS 連線，將刷卡紀錄、DHT11 溫濕度、MQ-135 數據編碼為 URL 字串，利用 RESTful API GET 請求每 10 秒批次上傳至 Google Apps Script。
- 每分鐘背景查詢中央氣象署 API，若所在地發生四級以上強震則通 知 Core 1 解鎖。
(四) 第四階段：雲端後端與 Web App 部署
- Google Apps Script (GAS)： 撰寫 doPost(e) 函式，解析 ESP32 傳來的參 數，並自動記錄至 Google Sheets。
- Google Sheets 資料庫： 設計自動化腳本，依據時間戳記（Timestamp）將 資料寫入對應欄位。
- Web App 介面： 使用 HTML5/CSS3 開發 RWD 響應式網頁，讓管理員可 透過瀏覽器即時查看全班手機格位的放置狀態與環境資訊。 (本專題部分程式碼除錯與優化由 Gemini 3 Pro 協助)

### 柒、 參考資料

一、記者林曉慧 沈志明 莊志成 (2025) 高中以下學生入校須交手機 教長：9 月起 實施
檢自:https://news.pts.org.tw/article/751302
二、記者林宏翰 (2024) 加州通過校園無手機法案 上課期間學生手機上鎖 檢自:https://www.cna.com.tw/news/aopl/202408310027.aspx
三、中天新聞 Facebook Reel/養機場太熱了...這樣手機會熟喔 檢自:https://www.facebook.com/reel/39261168694198
四、Google. (2025). Gemini 3 Pro [Large language model]. https://deepmind.google/technologies/gemini/

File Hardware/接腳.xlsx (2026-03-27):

ESP32 GPIO | 連接設備 | 備註
GPIO 35 | MQ-135 | 類比輸入 (A0)
GPIO 25 | DHT11 溫濕度 | 資料腳 (DATA)
GPIO 14 | 門磁感測器 | 另一腳接地 (Input Pullup)
GPIO 13 | 電磁鎖 (繼電器) | 觸發腳 (High Trigger)
GPIO 26 | 蜂鳴器 (+) | 長腳接26，短腳接地
GPIO 15 | TFT 螢幕 CS | SPI 片選
GPIO 2 | TFT 螢幕 DC | 資料/命令
GPIO 4 | TFT 螢幕 RST | 重置
GPIO 5 | RFID RC522 SDA(SS) | SPI 片選
GPIO 33 | RFID RC522 RST | 重置
GPIO 18 | TFT & RFID SCK | SPI 時鐘 (共用)
GPIO 23 | TFT & RFID MOSI | SPI 輸出 (共用)
GPIO 19 | TFT & RFID MISO | SPI 輸入 (共用)
GPIO 32 | Mega TX | Mega 2560 RX2 (串列接收)
GPIO 27 | Mega RX | Mega 2560 TX2 (串列發送)

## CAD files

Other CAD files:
Hardware/雷雕檔案/58x58.dxf

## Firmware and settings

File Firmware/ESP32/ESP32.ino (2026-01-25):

#include "ChineseFont.h" 
#include <WiFi.h>
#include <WiFiClientSecure.h>
#include <HTTPClient.h>
#include <SPI.h>
#include <MFRC522.h>
#include <Adafruit_GFX.h>
#include <Adafruit_ILI9341.h>
#include "HudScreen.h" 
#include "time.h"
#include <DHT.h> 

#define SCHEDULE_UNLOCK_DURATION 15000 

struct ScheduleTime { int hour; int minute; };
ScheduleTime unlockSchedule[30]; 
int scheduleCount = 0;           
int lastUnlockMinute = -1;       

#define DOOR_SENSOR_PIN 14  
#define AUTO_LOCK_HOLD_TIME 2000 
#define WARMUP_TIME 25000 

#define BUZZER_PIN 26          
#define BUZZER_TYPE 0  
#if BUZZER_TYPE == 0
  #define BUZZER_ON  LOW
  #define BUZZER_OFF HIGH
#else
  #define BUZZER_ON  HIGH
  #define BUZZER_OFF LOW
#endif

String MY_CITY = "輸入所在台灣縣市"; 
#define CWA_API_KEY "輸入中央氣象局api key"      
String CWA_URL = "https://opendata.cwa.gov.tw/api/v1/rest/datastore/E-A0015-001?Authorization=";

#define TFT_CS    15
#define TFT_DC     2
#define TFT_RST    4
#define SS_PIN     5    
#define RST_PIN   33   
#define RXD2      32   
#define TXD2      27   
#define valvePin  13 

#define MQ2_PIN   35  
#define DHT_PIN   25  
#define DHT_TYPE  DHT11

const int pwmFreq = 5000;
const int pwmResolution = 8;

#define PHYSICAL_POWER_DURATION 10000 
#define HIGH_POWER_DURATION     500   
#define LOGICAL_OPEN_DURATION   30000 
const unsigned long HEARTBEAT_INTERVAL = 60000;

const int level_GreenStart = 10;   
const int level_Yellow     = 50;   
const int level_Orange     = 90;   
const int fire_Threshold   = 110;  

const int SIGNAL_GAIN = 3; 

#define ILI9341_ORANGE 0xFD20 

const char* ssid = "輸入SSID名稱";
const char* password = "輸入Wifi密碼";
String G_SCRIPT_URL = "Google Apps Script 部署網址";

const char* ntpServer = "pool.ntp.org";
const long  gmtOffset_sec = 28800; 
const int   daylightOffset_sec = 0;

WiFiClientSecure secured_client;
MFRC522 rfid(SS_PIN, RST_PIN);
Adafruit_ILI9341 tft = Adafruit_ILI9341(TFT_CS, TFT_DC, TFT_RST);
HudScreen* hud;
DHT dht(DHT_PIN, DHT_TYPE);

uint16_t exactBgColor;

struct RFIDTag { uint8_t uid[4]; String name; };
struct RFIDTag tags[3] = { 
{{卡號}, "卡片名稱"} 
};
byte totalTags = sizeof(tags) / sizeof(RFIDTag);

bool isValvePowered = false;     
bool isLogicallyOpen = false;    
unsigned long valveOpenStartTime = 0;
unsigned long rfidCooldownTime = 0;    
float currentTemp = 0.0;
float currentHum = 0.0; 

int currentSmokeDiff = -1; 
int smokeBaseline = 0;    
float smoothedSmokeVal = 0;

bool isWarmedUp = false;
bool isEmergencyMode = false;
unsigned long emergencyStartTime = 0;
unsigned long lastQuakeCheckTime = 0;

bool lastDoorClosedState = false; 
bool isAutoLocking = false;   
bool isScheduleUnlock = false; 

volatile bool wifiReady = false;        
String sharedMegaMsg = "0";              
String sharedValveState = "0";           
volatile bool dataChanged = false;       
unsigned long lastUploadTime = 0;        
String lastAuthUser = "";

TaskHandle_t TaskUploadHandle;

void beep(int count) {
  for (int i = 0; i < count; i++) {
    digitalWrite(BUZZER_PIN, BUZZER_ON);
    delay(100); 
    digitalWrite(BUZZER_PIN, BUZZER_OFF);
    if (i < count - 1) delay(100); 
  }
}

void getLocalTimeStr(char* timeBuffer, char* dateBuffer) {
  struct tm timeinfo;
  if(!getLocalTime(&timeinfo)){
    strcpy(timeBuffer, "--:--");
    strcpy(dateBuffer, "----/--/--");
    return;
  }
  strftime(timeBuffer, 10, "%H:%M", &timeinfo);
  strftime(dateBuffer, 12, "%Y/%m/%d", &timeinfo); 
}

String urlEncode(String str) {
    String encodedString = "";
    char c; char code0; char code1;
    for (int i = 0; i < str.length(); i++) {
      c = str.charAt(i);
      if (c == ' ') encodedString += '+';
      else if (isalnum(c)) encodedString += c;
      else {
        code1 = (c & 0xf) + '0';
        if ((c & 0xf) > 9) code1 = (c & 0xf) - 10 + 'A';
        c = (c >> 4) & 0xf; code0 = c + '0';
        if (c > 9) code0 = c - 10 + 'A';
        encodedString += '%'; encodedString += code0; encodedString += code1;
      }
    }
    return encodedString;
}

void updateScheduleFromString(String payload) {
    if (payload.length() < 3) return;
    if (payload.indexOf("Error") >= 0 || payload.indexOf("Busy") >= 0) return;
    if (payload.indexOf(':') == -1) return;

    int index = 0;
    int arrayPos = 0;
    scheduleCount = 0; 

    while (index < payload.length() && arrayPos < 30) {
        int commaIndex = payload.indexOf(',', index);
        if (commaIndex == -1) commaIndex = payload.length();
        
        String timeStr = payload.substring(index, commaIndex); 
        int colonIndex = timeStr.indexOf(':');
        
        if (colonIndex > 0) {
            int h = timeStr.substring(0, colonIndex).toInt();
            int m = timeStr.substring(colonIndex + 1).toInt();
            unlockSchedule[arrayPos].hour = h;
            unlockSchedule[arrayPos].minute = m;
            arrayPos++;
        }
        index = commaIndex + 1;
    }
    scheduleCount = arrayPos;
}

void triggerUnlock(String line1, String line2, bool isSchedule) {
    Serial.println("Unlock: " + line1 + " " + line2);
    hud->updateLastUser(line1, line2);
    
    ledcWrite(valvePin, 255); 
    isValvePowered = true; 
    isLogicallyOpen = true; 
    isAutoLocking = false; 
    isScheduleUnlock = isSchedule; 
    
    valveOpenStartTime = millis(); 
    sharedValveState = "1"; 
    lastAuthUser = line1 + "|" + line2; 
    dataChanged = true;
}

bool performUpload(String megaData, String valveState, String user) {
  if (WiFi.status() == WL_CONNECTED) {
    HTTPClient http;
    String doorStatus = (digitalRead(DOOR_SENSOR_PIN) == HIGH) ? "0" : "1";
    Serial.print("Uploading... "); 

    String url = G_SCRIPT_URL + "?data=" + urlEncode(megaData) + 
                 "&valve=" + urlEncode(valveState) + 
                 "&temp=" + String(currentTemp, 1) +
                 "&hum=" + String(currentHum, 0) + 
                 "&smoke=" + String(currentSmokeDiff) + 
                 "&user=" + urlEncode(user) +
                 "&door=" + doorStatus; 

    http.setFollowRedirects(HTTPC_FORCE_FOLLOW_REDIRECTS);
    http.setTimeout(8000); 
    
    if (http.begin(secured_client, url)) {
      int httpCode = http.GET();
      if (httpCode > 0 && (httpCode == 200 || httpCode == 302)) {
          String response = http.getString();
          if (response.indexOf("CMD_UNLOCK") >= 0) {
              Serial.println("[CMD] Remote Unlock!");
              triggerUnlock("Remote", "Web User", false);
              beep(1); 
          }
          updateScheduleFromString(response);
          lastUploadTime = millis();
          Serial.println("Success");
          http.end();
          return true;
      }
      http.end();
    }
  } else {
    WiFi.reconnect();
  }
  return false;
}

void TaskUploadCode(void * pvParameters) {
  for(;;) { 
    if (wifiReady) {
      if (millis() - lastUploadTime > 3500) {
          bool needUpload = true; 
          if (needUpload) { performUpload(sharedMegaMsg, sharedValveState, lastAuthUser); }
      }
    }
    vTaskDelay(100 / portTICK_PERIOD_MS); 
  }
}

void lockTheDoor() {
    isValvePowered = false; 
    isLogicallyOpen = false;
    isAutoLocking = false; 
    isScheduleUnlock = false;
    ledcWrite(valvePin, 0); 
    sharedValveState = "0"; 
    lastAuthUser = ""; 
    dataChanged = true;
    Serial.println("System Locked.");
}

void triggerEmergency(String reason) {
  if (isEmergencyMode) return; 
  if (!isWarmedUp) return; 

  Serial.println("EMERGENCY: " + reason);
  isEmergencyMode = true;
  emergencyStartTime = millis();

  ledcWrite(valvePin, 255); 
  isValvePowered = true;
  valveOpenStartTime = millis(); 

  digitalWrite(BUZZER_PIN, BUZZER_ON);
  
  sharedValveState = "1";
  lastAuthUser = "System|EMERGENCY-" + reason;
  dataChanged = true;
}

void checkEarthquake() {
  if (String(CWA_API_KEY) == "") return;
  if (!isWarmedUp) return;
  if (WiFi.status() == WL_CONNECTED) {
    HTTPClient http;
    String url = CWA_URL + String(CWA_API_KEY) + "&limit=1&format=JSON";
    if (http.begin(url)) {
      int httpCode = http.GET();
      if (httpCode == 200) {
        String payload = http.getString();
        if (payload.indexOf(MY_CITY) > 0) {
           if (payload.indexOf("4級") > 0 || payload.indexOf("5弱") > 0 || payload.indexOf("5強") > 0 || payload.indexOf("6弱") > 0) {
               triggerEmergency("Quake(" + MY_CITY + ")");
           }
        }
      }
      http.end();
    }
  }
}

void checkSchedule() {
  if (scheduleCount == 0) return; 
  struct tm timeinfo;
  if(!getLocalTime(&timeinfo)){ return; }
  if (timeinfo.tm_min == lastUnlockMinute) return;
  if (timeinfo.tm_wday == 0 || timeinfo.tm_wday == 6) return;

  for(int i=0; i<scheduleCount; i++) {
    if (timeinfo.tm_hour == unlockSchedule[i].hour && 
        timeinfo.tm_min == unlockSchedule[i].minute) {
        String timeStr = String(timeinfo.tm_hour) + ":" + ((timeinfo.tm_min < 10) ? "0" : "") + String(timeinfo.tm_min);
        triggerUnlock("AUTOUNLOCK", timeStr, true);
        beep(1); 
        lastUnlockMinute = timeinfo.tm_min; 
        return;
    }
  }
  lastUnlockMinute = timeinfo.tm_min; 
}

void handleMegaSerial() {
  if (Serial2.available()) {
    String bestData = "";
    while (Serial2.available()) {
      String temp = Serial2.readStringUntil('\n');
      temp.trim();
      if (temp.length() > 0) {
        bestData = temp;
      }
    }
    if (bestData.length() > 0) {
      hud->updateCircles(bestData); 
      if (bestData != sharedMegaMsg) {
         sharedMegaMsg = bestData; 
         dataChanged = true; 
         Serial.println("Mega Updated: " + sharedMegaMsg);
      }
      Serial2.println("Ok");
    }
  }
}

void handleRFID() {
  unsigned long currentMillis = millis();
  
  if (isEmergencyMode) {
     if ((currentMillis / 200) % 2 == 0) digitalWrite(BUZZER_PIN, BUZZER_ON); 
     else digitalWrite(BUZZER_PIN, BUZZER_OFF);

     if (currentMillis - emergencyStartTime > 20000) {
        isEmergencyMode = false;
        digitalWrite(BUZZER_PIN, BUZZER_OFF); 
     }
  }

  int doorVal = digitalRead(DOOR_SENSOR_PIN); 
  bool currentDoorClosed = (doorVal == HIGH); 

  if (currentDoorClosed && !lastDoorClosedState) {
      ledcWrite(valvePin, 255); 
      isValvePowered = true;
      valveOpenStartTime = currentMillis; 
      isAutoLocking = true;
      dataChanged = true;
  }
  lastDoorClosedState = currentDoorClosed;

  if (isValvePowered) {
    if (isEmergencyMode) {
       if (currentMillis - valveOpenStartTime > HIGH_POWER_DURATION) {
          ledcWrite(valvePin, 135); 
       }
       valveOpenStartTime = currentMillis; 
    } else {
       if (currentMillis - valveOpenStartTime > HIGH_POWER_DURATION) {
          ledcWrite(valvePin, 135); 
       }
       unsigned long durationLimit = PHYSICAL_POWER_DURATION; 
       if (isAutoLocking) {
           durationLimit = AUTO_LOCK_HOLD_TIME; 
       } else if (isScheduleUnlock) {
           durationLimit = SCHEDULE_UNLOCK_DURATION;
       }
       if (currentMillis - valveOpenStartTime > durationLimit) {
          lockTheDoor();
       }
    }
  }

  if (isLogicallyOpen && (currentMillis - valveOpenStartTime > LOGICAL_OPEN_DURATION)) {
     if (!isEmergencyMode) {
       lockTheDoor();
     }
  }

  if (currentMillis - rfidCooldownTime < 1000) return; 
  if (!rfid.PICC_IsNewCardPresent()) return;
  if (!rfid.PICC_ReadCardSerial()) return;
  rfidCooldownTime = currentMillis;

  String uidStr = "";
  for (byte i = 0; i < rfid.uid.size; i++) {
    uidStr += String(rfid.uid.uidByte[i]);
    if (i < rfid.uid.size - 1) uidStr += "-";
  }
  
  bool foundTag = false;
  for (byte i = 0; i < totalTags; i++) {
    if (memcmp(tags[i].uid, rfid.uid.uidByte, rfid.uid.size) == 0) {
      foundTag = true;
      triggerUnlock(tags[i].name, uidStr, false); 
      beep(1); 
      break;
    }
  }
  if (!foundTag) {
      hud->updateLastUser("Access Denied", uidStr); 
      beep(2); 
  }
  rfid.PICC_HaltA(); rfid.PCD_StopCrypto1();
}

int readMQ2Median() {
  const int NUM_READS = 13; 
  int values[NUM_READS];
  for(int i=0; i<NUM_READS; i++) {
    values[i] = analogRead(MQ2_PIN);
    delay(2);
  }
  for(int i=0; i<NUM_READS-1; i++) {
    for(int j=0; j<NUM_READS-i-1; j++) {
      if(values[j] > values[j+1]) {
        int temp = values[j];
        values[j] = values[j+1];
        values[j+1] = temp;
      }
    }
  }
  return values[NUM_READS/2];
}

void waitForMegaSync() {
  Serial.println("Syncing with Mega...");
  unsigned long start = millis();
  while(millis() - start < 2000) {
    if (Serial2.available()) {
      String temp = Serial2.readStringUntil('\n');
      temp.trim();
      if (temp.length() > 0) {
        sharedMegaMsg = temp;
        if (sharedMegaMsg != "0") dataChanged = true;
        break;
      }
    }
    delay(50);
  }
}

void setup() {
  delay(1000); 
  Serial.begin(115200);

  pinMode(BUZZER_PIN, OUTPUT);
  beep(2); 

  tft.begin();
  tft.setRotation(1);
  exactBgColor = tft.color565(0, 70, 110); 
  tft.fillScreen(exactBgColor);
  hud = new HudScreen(&tft);
  hud->showBootConnecting(); 

  Serial2.begin(9600, SERIAL_8N1, RXD2, TXD2);
  Serial2.setTimeout(300); 
  waitForMegaSync();

  if (!ledcAttach(valvePin, pwmFreq, pwmResolution)) { Serial.println("PWM Fail"); }
  ledcWrite(valvePin, 0); 
  
  pinMode(MQ2_PIN, INPUT); 
  pinMode(DOOR_SENSOR_PIN, INPUT_PULLUP); 

  dht.begin();
  SPI.begin();
  rfid.PCD_Init();
  
  secured_client.setInsecure();
  WiFi.mode(WIFI_STA);
  WiFi.begin(ssid, password);
  
  int retry = 0;
  while (WiFi.status() != WL_CONNECTED && retry < 30) { delay(500); retry++; Serial.print("."); }
  
  if (WiFi.status() == WL_CONNECTED) {
    configTime(gmtOffset_sec, daylightOffset_sec, ntpServer);
    wifiReady = true; 
    hud->showBootSuccess(); 
    delay(1000);
    hud->showMain(); 
    hud->updateCircles(sharedMegaMsg);
    dataChanged = true; 
  } else {
    hud->showBootFailed();
    delay(2000);
    hud->showMain();
  }
  xTaskCreatePinnedToCore(TaskUploadCode, "UploadTask", 10000, NULL, 0, &TaskUploadHandle, 0);                
}

void loop() {
  handleMegaSerial();
  handleRFID();
  checkSchedule(); 
  
  if (millis() < WARMUP_TIME) {
      isWarmedUp = false;
      int remaining = (WARMUP_TIME - millis()) / 1000;
      static unsigned long lastWarmupUpdate = 0;
      if (millis() - lastWarmupUpdate > 1000) {
           float t = dht.readTemperature();
           float h = dht.readHumidity();
           if (!isnan(t)) { if (t < 0) t = -t; currentTemp = t; }
           if (!isnan(h) && h >= 0) { currentHum = h; }
           char timeBuf[10]; char dateBuf[12];
           getLocalTimeStr(timeBuf, dateBuf);
           hud->updateTimeTemp(currentTemp, currentHum, timeBuf, dateBuf);
           
           int ax = 200; int ay = 165; 
           tft.fillRect(ax, ay, 120, 20, exactBgColor);
           tft.setTextSize(2);
           tft.setCursor(ax, ay);
           tft.setTextColor(ILI9341_CYAN); 
           tft.print("Wait: " + String(remaining) + "s");
           lastWarmupUpdate = millis();
      }
      return; 
  }

  if (!isWarmedUp) {
      isWarmedUp = true;
      long sum = 0;
      for(int i=0; i<20; i++) { sum += readMQ2Median(); delay(10); }
      smokeBaseline = sum / 20;
      smoothedSmokeVal = smokeBaseline; 
      currentSmokeDiff = 0; 
      dataChanged = true;   
  }

  int rawAvg = readMQ2Median();
  smoothedSmokeVal = (smoothedSmokeVal * 0.6) + (rawAvg * 0.4);
  int diff = (int)smoothedSmokeVal - smokeBaseline;
  if (diff < 0) diff = 0; 
  diff = diff * SIGNAL_GAIN; 
  
  if (abs(diff - currentSmokeDiff) > 1 || diff > 20) {
      currentSmokeDiff = diff; 
      dataChanged = true; 
  }

  if (currentSmokeDiff >= fire_Threshold) { triggerEmergency("Fire"); }
  if (millis() - lastQuakeCheckTime > 60000) { checkEarthquake(); lastQuakeCheckTime = millis(); }

  static unsigned long lastUpdate = 0;
  static String lastAirStr = "";
  if (millis() - lastUpdate > 1000) {
      float t = dht.readTemperature();
      float h = dht.readHumidity();
      if (!isnan(t)) { if (t < 0) t = -t; currentTemp = t; }
      if (!isnan(h) && h >= 0) { currentHum = h; }
      char timeBuf[10]; char dateBuf[12];
      getLocalTimeStr(timeBuf, dateBuf);
      hud->updateTimeTemp(currentTemp, currentHum, timeBuf, dateBuf);
      
      String airStatus = "Air:Good!"; 
      uint16_t airColor = ILI9341_GREEN;
      if (currentSmokeDiff >= fire_Threshold) { airStatus = "Emergency!"; airColor = ILI9341_RED; }
      else if (currentSmokeDiff >= level_Orange) { airStatus = "Air:Bad"; airColor = ILI9341_ORANGE; }
      else if (currentSmokeDiff >= level_Yellow) { airStatus = "Air:Mid"; airColor = ILI9341_YELLOW; }
      else { airStatus = "Air:Good!"; airColor = ILI9341_GREEN; }
      
      if (airStatus != lastAirStr) {
          int ax = 200; int ay = 165; 
          tft.fillRect(ax, ay, 120, 20, exactBgColor);
          tft.setTextSize(2);
          tft.setCursor(ax, ay);
          tft.setTextColor(airColor);
          tft.print(airStatus);
          lastAirStr = airStatus;
      }
      lastUpdate = millis();
  }
}

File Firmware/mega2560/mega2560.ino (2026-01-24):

#include <Arduino.h>

// 定義 1~20 號對應的實體腳位 (雙號對應1-10，單號對應11-20)
const uint8_t pPort[] = {
  // 1~10 號 (雙號腳)
  28, 30, 32, 34, 36, 38, 40, 42, 44, 46,
  // 11~20 號 (單號腳)
  29, 31, 33, 35, 37, 39, 41, 43, 45, 47
};
const uint8_t N = sizeof(pPort) / sizeof(pPort[0]);

String lastSentState = "";
unsigned long lastForceSendTime = 0; // ★ 新增：用來計時的變數

void setup() {
  // 設定所有腳位為輸入模式
  for(int i=0; i<N; i++) {
    pinMode(pPort[i], INPUT);
  }
  
  pinMode(13, OUTPUT); // 內建 LED
  Serial.begin(115200); // 電腦監控用
  Serial1.begin(9600);  // 與 ESP32 通訊用
  Serial.println("Mega 2560 就緒 (含每秒自動更新功能)");
}

void loop() {
  String v = "";
  
  // 快速掃描 20 個腳位
  for (uint8_t i = 0; i < N; ++i) {
    if (digitalRead(pPort[i]) == LOW) { 
      v += String(i + 1) + ",";
    }
  }

  if (v.length() > 0) {
    v.remove(v.length() - 1);
  }

  unsigned long currentMillis = millis();

  // ★★★ 關鍵修改：除了狀態改變，每 1000ms (1秒) 也強制傳送一次 ★★★
  // 這樣 ESP32 剛開機或斷線重連後，馬上就能收到最新狀態
  if (v != lastSentState || (currentMillis - lastForceSendTime > 1000)) {
    
    // 更新記錄
    lastSentState = v;
    lastForceSendTime = currentMillis; // 重置計時器

    if (v.length() > 0) {
      Serial1.println(v);
      Serial.println("傳送: " + v);
    } else {
      Serial1.println("0");
      Serial.println("傳送: 0 (全空)");
    }
    
    // 閃燈提示有傳送資料
    digitalWrite(13, HIGH);
    delay(10);
    digitalWrite(13, LOW);
  }

  delay(50); // 掃描頻率
}

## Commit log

2026-01-24 Add initial firmware, hardware, and web app files
    Temperature Monitoring Function:
    The program defines TEMP_SENSOR_PIN 34 and uses an LM35 temperature sensor.
    It includes a readTemperature() function that converts voltage into degrees Celsius and uploads the temperature data to Google Sheets together with other data.
    Dual Door Lock Control Logic (Physical vs. Logical):
    Physical Power Cut: The electromagnetic lock is automatically powered off after being energized for 10 seconds (PHYSICAL_POWER_DURATION) to protect the hardware from damage.
    Logical State: Although the electromagnetic lock is powered off, the system logically keeps the door lock state as “open (1)” for 30 seconds (LOGICAL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
    [58x58.dxf, Mega2560_esp32S3.fzz, 接腳.xlsx]
2026-01-24 v2
    Detection Unit (Arduino Mega 2560):
    Due to the limited number of GPIO pins on the ESP32, the Arduino Mega is used to take advantage of its abundant pins (Pin 28–47) to connect 20 micro switches or infrared sensors.
    Signal Compression and Transmission:
    The Mega scans these 20 input pins and combines the triggered locker numbers into a string (e.g., “1,5,12”).
    The compressed data is sent to the ESP32 via Serial1 (TX1/RX1).
    Data is transmitted only when a state change occurs, conserving communication resources.
    Core Architecture and Task Allocation:
    A dual-core multitasking architecture is adopted, leveraging the ESP32’s FreeRTOS features to resolve network-related latency issues.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
    [ESP32.ino, HudScreen.h, mega2560.ino]
2026-01-24 v3
    1. Hardware Architecture and Sensor Upgrades
    The previous version used a simple analog temperature sensor, while the new version has been upgraded to a multifunctional environmental monitoring station:
    The LM35 temperature sensor has been replaced with a DHT11 temperature and humidity sensor.
    Smoke and air quality detection has been added using an MQ-135 sensor. When abnormal or excessive values are detected, a buzzer is triggered and the phone management cabinet is forcibly unlocked.
    A magnetic reed switch has been added to automatically lock the cabinet two seconds after the door is detected as closed.
    2. Four Major New Core Functions
    The new program introduces several advanced netw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
    [接腳.xlsx]
2026-01-25 v3.1
    1.新增ESP32 蜂鳴器回饋：
    刷卡成功：嗶 1 聲 (短促清脆)。
    刷卡失敗 (無授權)：嗶 2 聲 (警示音)。
    2.PIN 碼輸入時隱藏
2026-01-25 v3.2
    縮短輪詢間隔：ESP32 與 Google Sheets 的同步頻率由原本的 60 秒大幅縮短至 3.5 秒。
    即時反應：遠端解鎖指令的延遲從最長 1 分鐘降低至 4 秒內。
2026-01-25 Update Index.html
    更改PIN碼輸入邏輯
2026-03-27 補全文件
    [基礎電路圖.fzz, 接腳.xlsx]
2026-03-28 Create 運用雙微控制器與 Google Apps Script 雲端技術於智慧校園手機管理系統研製.pdf
